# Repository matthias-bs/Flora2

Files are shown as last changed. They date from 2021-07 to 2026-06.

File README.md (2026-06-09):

# Flora2
**ESP32 Irrigation System**

> [!NOTE]
> The MicroPython software implementation is now deprecated due to ongoing issues with out-of-memory conditions and other instabilities. Instead, a new Arduino sketch is provided. 

**flora2** (MicroPython) was a derivative of [**flora1**](https://github.com/matthias-bs/Flora1).

flora2

## Features
* Running on Espressif ESP32 Microcontroller ([HiLetgo ESP-WROOM-32 ESP32 ESP-32S Development Board](http://www.hiletgo.com/ProductDetail/1906566.html)) 
* [Arduino software](14_arduino/Flora2Arduino/README_ARDUINO.md) (**New!**)
* [MicroPython](https://micropython.org/) software (**Deprecated!**)
* Plant status monitorig
    * via Xiaomi Mi Flora Plant Sensors (Bluetooth Low Energy)
    * via capacitive Soil Moisture Sensors (wired)
* Tank low / Tank empty Status Monitoring with XKC-Y25-T12V (Non-Contact Liquid Level Sensor)
* Temperature Sensor [DS18B20](https://www.maximintegrated.com/en/products/sensors/DS18B20.html) (optional)
* Weather (i.e. Temperature, Barometric Pressure and Humidity) Sensors (optional)
    * [BME280](https://www.bosch-sensortec.com/products/environmental-sensors/humidity-sensors-bme280/)
    * [M5Stack ENV III](http://docs.m5stack.com/en/hat/hat_envIII) 
* Pump Control (5 or 12 Volts) with [Infineon BTS117](https://www.infineon.com/cms/en/product/power/smart-low-side-high-side-switches/low-side-switches/classic-hitfet-24v/bts117/) _N channel vertical power FET in Smart SIPMOS® technology_
* Automatic and manual Irrigation Control with one or two Pumps
* Power Supply from [Solar Power Manager](https://www.waveshare.com/wiki/Solar_Power_Manager) with Lithium-Ion Battery and [6 V/5 W Solar Panel](https://www.waveshare.com/Solar-Panel-6V-5W.htm) (optional)
* Battery Voltage Monitoring (optional)
* Controlling and Monitoring via MQTT over WiFi

## Dashboard with [IoT MQTT Panel](https://snrlab.in/iot/iot-mqtt-panel-user-guide) (Example)

IoTMQTTPanel_flora2o_s

## References

### Arduino Software

* [NimBLE-Arduino](https://github.com/h2zero/NimBLE-Arduino) &ndash; BLE central / GATT client
* [ArduinoJson](https://github.com/bblanchon/ArduinoJson) &ndash; JSON parsing and config
* [arduino-mqtt](https://github.com/256dpi/arduino-mqtt) &ndash; MQTT client
* [OneWireNg](https://github.com/pstolarz/OneWireNg) &ndash; DS18x OneWire driver (optional)
* [M5Unit-ENV](https://github.com/m5stack/M5Unit-ENV) &ndash; SHT3x + QMP6988 temperature, humidity & barometric pressure sensor driver for ENV III (optional)
* [pocketBME280](https://github.com/angrest/pocketBME280) &ndash; BME280 temperature, humidity & barometric pressure sensor driver (optional)

### MicroPython Software (deprecated)

* [micropython-umqtt.robust2](https://pypi.org/project/micropython-umqtt.robust2/)
* [MicroPython-MiFlora](https://github.com/matthias-bs/MicroPython-MiFlora)
* [micropython-bme280](https://github.com/kevbu/micropython-bme280)
* [MicroPython-Lib/DS18X20](https://github.com/micropython/micropython-lib/tree/master/micropython/drivers/sensor/ds18x20)
* [M5_ENVIII - micropython libraries for SHT30 and QMP6988](https://github.com/cdrajb/M5_ENVIII)

----

## Disclaimer and Legal

> *Xiaomi* and *Mi Flora* are registered trademarks of *BEIJING XIAOMI TECHNOLOGY CO., LTD.*
>
> This project is a community project not for commercial use.
> The authors will not be held responsible in the event of device failure or withered plants.
>
> This project is in no way affiliated with, authorized, maintained, sponsored or endorsed by *Xiaomi* or any of its affiliates or subsidiaries.

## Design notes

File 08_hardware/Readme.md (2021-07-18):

# flora2 - Hardware

## Files
<table>
<thead>
  <tr>
    <th>File</th>
    <th>Description</th>
  </tr>
</thead>
<tbody>
  <tr>
    <td><a href="https://github.com/matthias-bs/Flora2/blob/main/08_hardware/flora2.fzz" target="_blank" rel="noopener noreferrer">flora2.fzz</a></td>
    <td>Fritzing Schematic and PCB</td>
  </tr>
  <tr>
    <td><a href="https://github.com/matthias-bs/Flora2/blob/main/08_hardware/flora2_pcb.pdf" target="_blank" rel="noopener noreferrer">flora2_pcb.pdf</a></td>
    <td>Printed Circuit Board<br></td>
  </tr>
  <tr>
    <td><a href="https://github.com/matthias-bs/Flora2/blob/main/08_hardware/flora2_sch.pdf" target="_blank" rel="noopener noreferrer">flora2_sch.pdf</a></td>
    <td>Schematic</td>
  </tr>
  <tr>
    <td><a href="https://github.com/matthias-bs/Flora2/blob/main/08_hardware/flora2_pcb_v1.0p1_patch_q4.pdf" target="_blank" rel="noopener noreferrer">flora2_pcb_v1.0p1_patch_q4.pdf</a></td>
    <td>Description of Patch p1 (Q4 Pin Mismatch)</td>
  </tr>
  <tr>
    <td><a href="https://github.com/matthias-bs/Flora2/blob/main/08_hardware/flora2_pcb_v1.0p1_patch_q4.png" target="_blank" rel="noopener noreferrer">flora2_pcb_v1.0p1_patch_q4.png</a></td>
    <td>Description of Patch p1 (Q4 Pin Mismatch)</td>
  </tr>
</tbody>
</table>

## Bugs

- Distance between D1-4 and nearby resistors too small
- U1 (voltage regulator) blocks access to Micro-USB connector
- PCB for case "BOPLA EM 220 F" too wide
  
  B_actual:  75,5
  
  B_target: 73,0
  
  -> using "BOPLA EM 217 F" instead
  
- No mounting holes for case "BOPLA EM 220 F"

  -> using "BOPLA EM 217 F" with base plate ([dxf](../12_mounting/flora2_base_plate.dxf) | [pdf](../12_mounting/flora2_base_plate.pdf))

- Wrong footprint for U1 ESP32 DevKit
  
  B_actual:  22,86mm (fits [HiLetgo ESP-32S](http://www.hiletgo.com/ProductDetail/1906566.html)!)
  
  B_target: 25,25mm (fits AZ-Delivery ESP32-DevKitC V4/JoyIt NodeMCU ESP32)
  
- Wrong footprint for Q4 ZVP2106A (**see patch p1**)
- Add pull-down resistor 10 kOhm at gate of Q3, otherwise Sensor_PWR_int wpuld be active in Deep-Sleep-Mode (**see patch p1**)

**Patch p1**
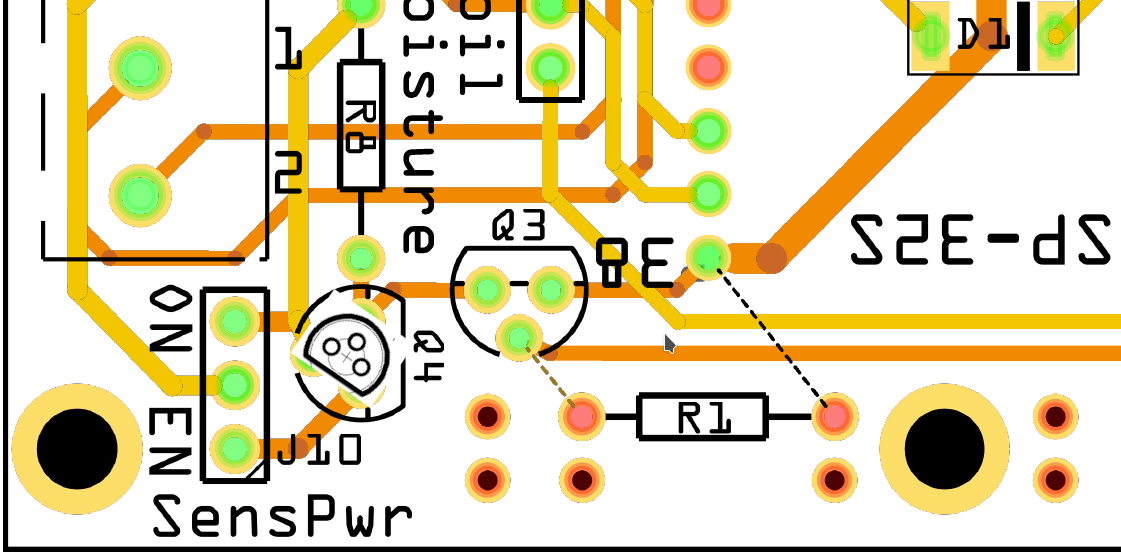
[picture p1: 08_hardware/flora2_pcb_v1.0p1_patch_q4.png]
Patch p1


## Open Issues
- add capacitors 100nF parallel to ADC inputs
- add voltage divider for Ubatt measurement as assembly option: R10=200k, R11=100k (opt.) 
- add DS18B20 + pull-up resistor 4k7 (opt.)
- add pull-down resistors for pump drivers (opt.)
- reduce Standby-Power in Deep-Sleep-Mode (opt.)
    - remove R10 or LED2 (red) from ESP-32S module

## Copyright Notice
Image: https://de.123rf.com/lizenzfreie-bilder/90587529.html

Name:

(de) Gießkanne und Blumen in Töpfen. Bewässerungssymbol lokalisiert auf weißem Hintergrund

(en) Watering can and flowers in pots. Irrigation symbol isolated on white background

File No.: 90587529

Copyright: [nikolae](https://www.123rf.com/profile_nikolae/)

Please check license on 123RF when using the image. Using the image as silkscreen print on PCB for non-commercial purposes was agreed upon by 123RF.

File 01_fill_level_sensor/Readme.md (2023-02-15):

# flora2 Tank Level Sensors

[DFRobot SEN0204 Non-contact Liquid Level Sensor XKC-Y25-T12V](https://wiki.dfrobot.com/Non-contact_Liquid_Level_Sensor_XKC-Y25-T12V_SKU__SEN0204)

Or use your favourite search engine to find the manual/"datasheet" and a supplier for the sensor **XKC Y25 T12V**. The original manufacturer seems to be hard to find...

XKC_Y25_T12V Front View

XKC_Y25_T12V Front View

XKC_Y25_T12V Back View
(I am using velcro tape to attach the sensors to the tank.)

XKC_Y25_T12V Back View

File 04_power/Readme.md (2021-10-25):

# flora2 Power Supply & Power Management

## Solar Power

https://www.waveshare.com/solar-power-manager.htm

https://www.waveshare.com/Solar-Panel-6V-5W.htm

**Note 1:**

The Solar Power Manager can supply up to 1A @5V. Please make sure that the controller (with sensors) and pump(s) do not exceed this limit.

### Battery Voltage Measurement

For battery voltage measurement, an additional wire has to be soldered to the Solar Power Manager (net label *VBAT* in the schematic, see #1 in the photo below). A small resistor (e.g. 10 Ohms) in series to the U_bat output should be added to avoid high currents in case of a short circuit.

_waveshare_solar_power_manager-1

On the flora2 PCB, an analog moisture input has to be used for voltage measurement. The following changes have to be made to adapt the battery voltage to the Analog-to-Digital Converter (ADC) input voltage range (see [Schematic](https://github.com/matthias-bs/Flora2/blob/main/08_hardware/flora2_sch.pdf)).

**Moisture4 Input -> U_bat Input**

<table>
  <tr>
    <th>Part
    <th>Value for Moisture4
    <th>Value for U_bat
  </tr>
  <tr>
    <td>R16
    <td>220k
    <td>200k
  </tr>
    <tr>
    <td>R17
    <td>330k || 100nF
    <td>100k || 100nF
  </tr>
</table>

### Battery Power Optimization

In order to save battery power, some parts of the Solar Power Manager can be modified by cutting PCB traces:
1. disconnect Battery Charge Indicator U3 with LED7..10 (see #2 in photo above)
2. disconnect Power LED (LED11, see #3 in photo below)

_waveshare_solar_power_manager-2

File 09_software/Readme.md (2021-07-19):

# flora2 Software

## Open Issues

- Sending Email reports works only partly (depending on configuration)

    Sending Email works only if sufficient memory is available due to the relative high SSL memory requirements. For example, a configuration with three analog moisture sensor leaves enough memory, another with two Miflora BLE sensor does not. At least the program handles the out-of-memory exception gracefully.

- Secure MQTT (MQTT over TLS) is kind of buggy

    As far as the MicroPython documentation goes, using the SSL Socket Wrapper or not should not make a big difference (except for memory requirements). But in fact it does! It seems the SSL Socket Object behaves different from the normal SSL Sockets regarding exceptions and polling. I racked my brain for quite a while to pin down the problem and to find a solution - to no avail yet. The current workaround is still not convincing.
    
- Compatibility to CPython / Raspberry Pi broken

    At some point, compatibility was left behind due to tweaking the code to run on **MicroPython / ESP32** - and partly in favor of new features. With some efforts, it should be possible to re-establish compatibility to **CPython / Raspberry Pi**. As a first step, the code could be modified to run on **MicroPython / Raspberry Pi**.
    The sources are quite cluttered with conditional sections concerning MicroPython and ESP32. GPIO handling is one of the inglorious examples...

Some minor points:
- Night Time Detection deserves some clean-up
- Logging / Debug Printing depending on VERBOSITY could be improved
- Wi-Fi Manager integration failed due to lack of memory
- Garbage collection is basically integrated by trial-and-error 

## Configuration

- [**secrets.py**](secrets.py) must be modified according to your WiFi, MQTT and SMTP configuration!!!
- [**config.ini**](config.ini) must be modified according to your hardware setup, plants and personal taste!
- It might be necessary to modify [**config.py**](config.py), too.

## Files

**Note:**

Due to ESP32's memory restrictions, the Python source code (**.py**) must be compiled to bytecode (**.mpy**) using **mpy-cross** (see  [MicroPython Glossary - cross-compiler](https://docs.micropython.org/en/latest/reference/glossary.html#term-cross-compiler)).

<table>
<thead>
  <tr>
    <th>File</th>
    <th>Description</th>
  </tr>
</thead>
<tbody>
  <tr>
    <td>adc1_cal.py</td>
    <td>MicroPython ESP32 ADC1 conversion using V_ref calibration value</td>
  </tr>
  <tr>
    <td>alert.py</td>
    <td>Alert class; detects Changes / Range Violations of Sensor Data and System Status, implements filter to control frequency of Email Reports</td>
  </tr>
  <tr>
    <td>bme280.py</td>
    <td>BME280 Temperature/Barometric Pressure/Humidity Sensor Library</td>
  </tr>
  <tr>
    <td>boot.py</td>
    <td>Empty MicroPython Boot Code</td>
  </tr>
  <tr>
    <td>ConfigParser.py</td>
    <td>Minimal and Functional Version of CPython's ConfigParser Module</td>
  </tr>
  <tr>
    <td>config.ini</td>
    <td><b>User's Configuration File</b></td>
  </tr>
  <tr>
    <td>config.py</td>
    <td><b>Default application settings and the Settings class with attributes from the configuration file</b></td>
  </tr>
  <tr>
    <td>flora_email.py</td>
    <td>Email class; a wrapper around umail or email.message, respectively</td>
  </tr>
  <tr>
    <td>flora_mqtt.py</td>
    <td>flora2 MQTT functions</td>
  </tr>
  <tr>
    <td>garbage_collect.py</td>
    <td>gcollect() and meminfo() Helper Functions</td>
  </tr>
  <tr>
    <td>gpio.py</td>
    <td>A stub (i.e. non-functional(!) replacement) for RPi.GPIO on other systems than Raspberry Pi</td>
  </tr>
  <tr>
    <td>irrigation.py</td>
    <td>Irrigation class; manual and automatic Irrigation</td>
  </tr>
  <tr>
    <td>main.py</td>
    <td>flora2 Main Code</td>
  </tr>
  <tr>
    <td>miflora.py</td>
    <td>MicroPython Library for Xiaomi Mi Flora (aka. flower care) BLE Plant Sensors</td>
  </tr>
  <tr>
    <td>moisture.py</td>
    <td>Moisture class; analog Moisture Sensor Reading</td>
  </tr>
  <tr>
    <td>print_line.py</td>
    <td>print_line() function; printing with time stamp and some formatting</td>
  </tr>
  <tr>
    <td>pump.py</td>
    <td>Pump class; Pump hardware control/status, software busy flag and timestamp</td>
  </tr>
  <tr>
    <td>report.py</td>
    <td>Report class; generates HTML report with various sensor/plant and system data</td>
  </tr>
  <tr>
    <td>secrets.py</td>
    <td><b>User defined constants to be kept secret</b></td>
  </tr>
  <tr>
    <td>sensor_power.py</td>
    <td>Sensor_Power class; controls the sensor power via GPIO</td>
  </tr>
  <tr>
    <td>sensor.py</td>
    <td>Sensor class; stores sensor and plant data, compares sensor data with plant data and checks sensor battery and data validity</td>
  </tr>
  <tr>
    <td>tank.py</td>
    <td>Tank class; tank fill level status values <low> and <empty> according to sensor outputs via GPIO pins</td>
  </tr>
  <tr>
    <td>temperature.py</td>
    <td>MicroPython Temperature class; DS18x20 OneWire Temperature Sensor Value</td>
  </tr>
  <tr>
    <td>umail.py</td>
    <td>uMail (MicroMail) for MicroPython</td>
  </tr>
  <tr>
    <td>weather.py</td>
    <td>Weather Sensor Data; temperature, humidity and barometric pressure from BME280 sensor connected to I2C bus interface</td>
  </tr>
  <tr>
    <td>wifi.py</td>
    <td>WiFi Connection Functions</td>
  </tr>
</tbody>
</table>

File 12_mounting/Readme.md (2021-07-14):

# flora2 Mounting Parts

<table>
    <tr>
      <th>File<th>Description
    </tr>
    <tr>
      <td>flora2_base_plate [<a href="flora2_base_plate.pdf">.pdf</a> | <a href="flora2_base_plate.dxf">.dxf</a>]
      <td>Base Plate for Mounting flora2 PCB to <a href="https://www.bopla.de/en/enclosure-technology/product/euromas-ii/-1/em-217-f.html">Bopla EM 217 F</a> Case
    </tr>
    <tr>
      <td>flora2_charger+batt [<a href="flora2_charger+batt.dxf">.dxf</a>]
      <td>Mounting Plate for <a href="https://www.bopla.de/en/enclosure-technology/product/euromas-ii/-1/em-220-f.html">Bopla EM 220 F</a> Case; Solar Power Manager and 18650 Li-Ion Cell
    </tr>
    <tr>
      <td>flora2_solar [<a href="flora2_solar.dxf">.dxf</a>]
      <td>Mounting Plate for <a href="https://www.waveshare.com/Solar-Panel-6V-5W.htm">Waveshare 6 V/5 W Solar Panel</a>
    </tr>
</table>

Size 5 hydraulic pipe clamps (acc. to DIN 3015-Part 1) can be used to fix the solar cell and charger/battery mounting plates to a 42mm balcony railing -- well, something less sophisticated might be sufficient...

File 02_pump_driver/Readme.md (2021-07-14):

# flora2 Pump Drivers

See [Infineon BTS117](https://www.infineon.com/cms/en/product/power/smart-low-side-high-side-switches/low-side-switches/classic-hitfet-24v/bts117/) _N channel vertical power FET in Smart SIPMOS® technology_ manual/datasheet.
Ensure matching power supply and pump voltages. Check that your power supply's current capability matches the pumps' current requirements -- the initial currents may exceed the nominal currents.

## Note:

The pump drivers are low-side switches -- connect pump's **plus**-wire to **positive connector of power supply** and pump's **minus**-wire to PCB terminal **P1** or **P2**, respectively.

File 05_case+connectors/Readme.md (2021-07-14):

# flora2 Case & Connectors

<table>
    <tr>
      <th>File<th>Description
    </tr>
    <tr>
      <td>flora2_outdoor_front_rev02 [<a href="outdoor/flora2_outdoor_front_rev02.pdf">.pdf</a> | <a href="outdoor/flora2_outdoor_front_rev02.dxf">.dxf</a>]
      <td>Front Plate Drilling for <a href="https://www.bopla.de/en/enclosure-technology/product/euromas-ii/-1/em-217-f.html">Bopla EM 217 F</a> Case
    </tr>
    <tr>
      <td>flora2_outdoor_label_rev01 [<a href="outdoor/flora2_outdoor_label_rev01.pdf">.pdf</a> | <a href="outdoor/flora2_outdoor_label_rev01.odg">.odg</a>]
      <td>Label for <a href="https://www.bopla.de/en/enclosure-technology/product/euromas-ii/-1/em-217-f.html">Bopla EM 217 F</a> Case Top
    </tr>
    <tr>
      <td>flora2_outdoor_wiring_rev02 [<a href="outdoor/flora2_outdoor_wiring_rev02.pdf">.pdf</a> | <a href="outdoor/flora2_outdoor_wiring.odg">.odg</a>]
      <td>PCB to Connectors Wiring Table</a>
    </tr>
</table>

## Note:

The pump drivers are low-side switches -- connect pump's **plus**-wire to **positive connector of power supply** and pump's **minus**-wire to PCB terminal **P1** or **P2**, respectively.

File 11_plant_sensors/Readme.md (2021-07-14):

# flora2 Plant Sensors

## Xiaomi Mi Flora Plant Sensor
Please refer to https://xiaomi-mi.com/home/user-manuals/ and search for *Huahuacacao Flower Care Smart Monitor* - or use your favourite search engine with the keywords *Mi Flora Plant Sensor* or *Mi Flora Flower Care* for manual/datasheet.

Mi Flora Plant Sensor

## Capacitive Soil Moisture Sensor

Use your favourite search engine with the keywords *Capacitive Soil Moisture Sensor V1.2*. For low noise add a 100nF capacitors parallel to each ADC input (i.e. parallel to R11/R13/R15/R17).

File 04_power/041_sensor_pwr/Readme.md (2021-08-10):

# LTspice Simulation of Sensor Power Circuit (Q3/Q4)

## Introduction

The LTspice simulation was done, because the sensor power circuit initially did not work. It proved that the circuit was designed properly. Further investigation revealed the Q4 footprint mismatch (see https://github.com/matthias-bs/Flora2/blob/main/08_hardware/Readme.md). 

## Setup

<table>
<thead>
  <tr>
    <th>File</th>
    <th>Description</th>
  </tr>
</thead>
<tbody>
  <tr>
    <td><a href="ZVN4206A.net" target="_blank" rel="noopener noreferrer">ZVN4206A.net</a></td>
    <td>ZETEX ZVN4206A spice model (from https://www.diodes.com/part/view/ZVN4206A)</td>
  </tr>
  <tr>
    <td><a href="ZVP2106A.net" target="_blank" rel="noopener noreferrer">ZVP2106A.net</a></td>
    <td>ZETEX ZVP2106A spice model (from https://www.diodes.com/part/view/ZVP2106A)</td>
  </tr>
  <tr>
    <td><a href="ZVN4206A.asy" target="_blank" rel="noopener noreferrer">ZVN4206A.asy</a></td>
    <td>LTspice symbol for ZVN4206A (using ZVN4206A model file)</td>
  </tr>
  <tr>
    <td><a href="ZVP2106A.asy" target="_blank" rel="noopener noreferrer">ZVP2106A.asy</a></td>
    <td>LTspice symbol for ZVP2106A (using ZVP2106A model file)</td>
  </tr>
  <tr>
    <td><a href="sensor_pwr.net" target="_blank" rel="noopener noreferrer">sensor_pwr.net</a></td>
    <td>Netlist</td>
  </tr>
  <tr>
    <td><a href="sensor_pwr.asc" target="_blank" rel="noopener noreferrer">sensor_pwr.asc</a></td>
    <td>LTspice schematic</td>
  </tr>
  <tr>
    <td><a href="sensor_pwr.plt" target="_blank" rel="noopener noreferrer">sensor_pwr.plt</a></td>
    <td>LTspice plot parameters</td>
  </tr>
  <tr>
    <td><a href="sensor_pwr.pdf" target="_blank" rel="noopener noreferrer">sensor_pwr.pdf</a></td>
    <td>Simulation plot (PDF)</td>
  </tr>
</tbody>
</table>

## Schematic
sensor_pwr_schematic

Sensor Power Switch Circuit (Load: 50 Ohms)

sensor_pwr_w_parameter_schematic

Sensor Power Switch Circuit (Load: [45 50 55 500] Ohms)

## Simulation Results

sensor_pwr_plt

Simulation Plot (Load: 50 Ohms)

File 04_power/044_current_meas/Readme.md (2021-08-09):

# Measurements

## Setup
current_measurement_setup
[Probe Image: https://commons.wikimedia.org/wiki/File:WTPC_Oscilloscope-1.jpg]

Shunt: Vishay RS-2C 0,1 Ohm / 0,5% / 2,5W
Marker: J9/Pin 9 - GPIO 0 (Pullup)

## PicoSope Settings
Ch A +/- 500mV DC
Ch B +/- 5V DC
50 s/div

Trigger B, rising edge, 1,0V 5%
Measurements: Ch A - DC Average - Between Rulers

[20210613-flora2o.pssettings](https://github.com/matthias-bs/Flora2/blob/main/04_power/044_current_meas/20210613-flora2o.pssettings)

## SW Marker

<table>
<tr>
    <th>Marker<th>Level<th>Code Section
</tr>
<tr>
    <td>#0<td>1<td>Boot done
</tr>
<tr>
    <td>#1<td>0<td>WiFi on
</tr>
<tr>
    <td>#2<td>1<td>MQTT init done
</tr>
<tr>
    <td>#3<td>0<td>Start main loop
</tr>
<tr>
    <td>#4<td>1<td>BLE start
</tr>
<tr>
    <td>#5<td>0<td>BLE end
</tr>
<tr>
    <td>#6<td>1<td>Deep sleep (Pull up)
</tr>
</table>
  
## Results

### Summary

**(flora2o-20210613-pump_off)**

- AVG (-0.05  ;0:00  ) = 3,26 mA (Deep Sleep)
- AVG ( 0:00  ;1:02  ) = 76 mA (active)
- AVG ( 0:08  ;0:09.3) = 100 mA (max. WiFi activity)
- AVG ( 0:24.3;0:46.2) = 92 mA (BLE active)

### Measurement Data

<table>
<thead>
  <tr>
    <th>File</th>
    <th>Description</th>
  </tr>
</thead>
<tbody>
  <tr>
    <td><a href="flora2o-20210613-pump_off.psdata" target="_blank" rel="noopener noreferrer">flora2o-20210613-pump_off.psdata</a></td>
    <td>Pumps off</td>
  </tr>
  <tr>
    <td><a href="flora2o-20210613-pump_1.psdata" target="_blank" rel="noopener noreferrer">flora2o-20210613-pump_1.psdata</a></td>
    <td>Pump 1 on</td>
  </tr>
  <tr>
    <td><a href="flora2o-20210613-pump_2.psdata" target="_blank" rel="noopener noreferrer">flora2o-20210613-pump_2.psdata</a></td>
    <td>Pump 2 on</td>
  </tr>
  <tr>
    <td><a href="flora2o-20210613-pump_off-solar.psdata" target="_blank" rel="noopener noreferrer">flora2o-20210613-pump_off-solar.psdata</a></td>
    <td>Solar power supply</td>
  </tr>
</tbody>
</table>

### Waveforms

<table>
<thead>
  <tr>
    <th>File</th>
    <th>Description</th>
  </tr>
</thead>
<tbody>
  <tr>
    <td><a href="waveforms/flora2o-20210613-pump_off-total_avg.pdf" target="_blank" rel="noopener noreferrer">flora2o-20210613-pump_off-total_avg.pdf</a></td>
    <td>Complete cycle, pumps off; average current</td>
  </tr>
  <tr>
    <td><a href="waveforms/flora2o-20210613-pump_off-active.pdf" target="_blank" rel="noopener noreferrer">flora2o-20210613-pump_off-active.pdf</a></td>
    <td>Complete cycle - active phase, pumps off; average current</td>
  </tr>
  <tr>
    <td><a href="waveforms/flora2o-20210613-pump_off-sleep_mode.pdf" target="_blank" rel="noopener noreferrer">flora2o-20210613-pump_off-sleep_mode.pdf</a></td>
    <td>Sleep mode; average current</td>
  </tr>
  <tr>
    <td><a href="waveforms/flora2o-20210613-pump_off-ble.pdf" target="_blank" rel="noopener noreferrer">flora2o-20210613-pump_off-ble.pdf</a></td>
    <td>BLE activity; average current</td>
  </tr>
  <tr>
    <td><a href="waveforms/flora2o-20210613-pump_off-ble_time.pdf" target="_blank" rel="noopener noreferrer">flora2o-20210613-pump_off-ble_time.pdf</a></td>
    <td>BLE activity; communication duration<br></td>
  </tr>
  <tr>
    <td><a href="waveforms/flora2o-20210613-pump_off-wifi.pdf" target="_blank" rel="noopener noreferrer">flora2o-20210613-pump_off-wifi.pdf</a></td>
    <td>WiFi activity; average current</td>
  </tr>
  <tr>
    <td><a href="waveforms/flora2o-20210613-pump_off-wifi_peak.pdf" target="_blank" rel="noopener noreferrer">flora2o-20210613-pump_off-wifi_peak.pdf</a></td>
    <td>WiFi activity; peak current</td>
  </tr>
  <tr>
    <td><a href="waveforms/flora2o-20210613-pump1-total_avg.pdf" target="_blank" rel="noopener noreferrer">flora2o-20210613-pump1-total_avg.pdf</a></td>
    <td>Complete cycle with pump 1 on; average current</td>
  </tr>
  <tr>
    <td><a href="waveforms/flora2o-20210613-pump1-avg%2Bmax.pdf" target="_blank" rel="noopener noreferrer">flora2o-20210613-pump1-avg+max.pdf</a></td>
    <td>Pump 1 on; average and max. current</td>
  </tr>
  <tr>
    <td><a href="waveforms/flora2o-20210613-pump1-ec_cycle.pdf" target="_blank" rel="noopener noreferrer">flora2o-20210613-pump1-ec_cycle.pdf</a></td>
    <td>Pump 1 on; electronic commutation cycle time</td>
  </tr>
  <tr>
    <td><a href="waveforms/flora2o-20210613-pump2-total_avg.pdf" target="_blank" rel="noopener noreferrer">flora2o-20210613-pump2-total_avg.pdf</a></td>
    <td>Complete cycle with pump 2 on; average current</td>
  </tr>
  <tr>
    <td><a href="waveforms/flora2o-20210613-pump2-avg+max.pdf" target="_blank" rel="noopener noreferrer">flora2o-20210613-pump2-avg+max.pdf</a></td>
    <td>Pump 2 on; average and max. current</td>
  </tr>
  <tr>
    <td><a href="waveforms/flora2o-20210613-pump2-ec_cycle.pdf" target="_blank" rel="noopener noreferrer">flora2o-20210613-pump2-ec_cycle.pdf</a></td>
    <td>Pump 2 on; electronic commutation cycle time<br></td>
  </tr>
  <tr>
    <td><a href="waveforms/flora2o-20210613-solar_pwr-noise.pdf" target="_blank" rel="noopener noreferrer">flora2o-20210613-solar_pwr-noise.pdf</a></td>
    <td>Solar power supply; current noise (min./max./avg.)</td>
  </tr>
  <tr>
    <td><a href="waveforms/flora2o-20210613-solar_pwr-noise_T.pdf" target="_blank" rel="noopener noreferrer">flora2o-20210613-solar_pwr-noise_T.pdf</a></td>
    <td>Solar power supply; current noise timing</td>
  </tr>
  <tr>
    <td><a href="waveforms/flora2o-20210613-solar_pwr-noise_f.pdf" target="_blank" rel="noopener noreferrer">flora2o-20210613-solar_pwr-noise_f.pdf</a></td>
    <td>Solar power supply; current noise frequency</td>
  </tr>
</tbody>
</table>

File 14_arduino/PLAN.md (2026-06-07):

# Flora2Arduino — Implementation Plan

Port of `09_software/_main.py` (MicroPython) to an Arduino/C++ sketch targeting the
ESP32 DevKit.

---

## Goals

| # | Goal |
|---|---|
| 1 | Preserve all run-time behaviour of the MicroPython version |
| 2 | Keep module boundaries so each subsystem is independently testable |
| 3 | Compile-time feature flags replace the `config.ini` `[...]_en` booleans |
| 4 | `RTC_DATA_ATTR` replaces `machine.RTC().memory()` for deep-sleep persistence |
| 5 | MQTT (arduino-mqtt) + optional HA discovery replaces `paho-mqtt` |

---

## Target Hardware

| Signal | GPIO | Notes |
|---|---|---|
| Moisture sensor 1 | 34 | ADC1 ch6, input-only |
| Moisture sensor 2 | 36 | ADC1 ch0 (SVP), input-only — avoids GPIO 35 conflict |
| Moisture sensor 3 | 32 | ADC1 ch4 |
| Moisture sensor 4 | 33 | ADC1 ch5 |
| Pump relay 1 | 19 | HIGH = on |
| Pump relay 2 | 18 | HIGH = on |
| Tank LOW switch | 23 | HIGH = triggered |
| Tank EMPTY switch | 21 | HIGH = triggered |
| Sensor power rail | 27 | HIGH = VCC on (I2C + 1-Wire) |
| DS18B20 OneWire | 5 | Optional |
| I2C SDA | 26 | ENV III / BME280 |
| I2C SCL | 25 | ENV III / BME280 |
| Battery ADC | 35 | ADC1 ch7, 100 kΩ / 200 kΩ divider → 1/3 of V_BAT |

---

## File Layout

```
Flora2Arduino/
├── Flora2Arduino.ino       Main sketch (setup / loop)
├── Flora2Cfg.h             GPIO pins, feature flags, compile-time defaults,
│                           PlantSensorData + WeatherData structs
├── secrets.h               WiFi network array, MQTT credentials, TIMEZONE_STR,
│                           NTP server list  (not committed)
├── secrets.h.example       Template for secrets.h
├── data/
│   └── config.json         Runtime config (uploaded to LittleFS)
└── src/
    ├── ConfigLoader.h/.cpp  Load AppConfig from LittleFS JSON, with defaults
    ├── Tank.h/.cpp          TankStatus (OK/LOW/EMPTY) from two GPIO inputs
    ├── Pump.h/.cpp          Timed relay with tank-abort + MQTT keep-alive CB
    ├── MoistureSensor.h/.cpp analogReadMilliVolts() → % (linear calibration)
    ├── DS1820.h/.cpp        OneWireNg_CurrentPlatform + DSTherm driver (Placeholder, no global ctor)
    ├── WeatherSensor.h/.cpp  ENV III (SHT3X + QMP6988) or BME280, I2C
    ├── MiFloraSensor.h/.cpp  NimBLE passive scan + TheengsDecoder + GATT battery
    ├── Irrigation.h/.cpp     Auto/manual irrigation logic
    ├── WiFiManager.h/.cpp    Multi-network connect, NTP sync
    └── MqttManager.h/.cpp    MQTT pub/sub, LWT, optional HA discovery
```

---

## Required Libraries

| Library | Author | Purpose |
|---|---|---|
| NimBLE-Arduino v2 | h2zero | BLE passive scan + GATT client |
| TheengsDecoder | theengs | Decode raw MiFlora advertisement JSON |
| ArduinoJson | bblanchon | config.json parsing, TheengsDecoder |
| arduino-mqtt | 256dpi | MQTT client (MQTTClient) |
| OneWireNg | pstolarz | 1-Wire bus driver + DS18xx `DSTherm` driver |
| M5Unit-ENV | m5stack | SHT3X + QMP6988 (`#ifdef WEATHER_SENSOR_ENV3`) |
| pocketBME280 | angrest | BME280 (`#ifdef WEATHER_SENSOR_BME280`) |

---

## Feature Flags (`Flora2Cfg.h`)

| Flag | Effect |
|---|---|
| `WEATHER_SENSOR_ENV3` | Include M5Unit-ENV driver (SHT3X + QMP6988) |
| `WEATHER_SENSOR_BME280` | Include Adafruit BME280 driver |
| `TEMPERATURE_SENSOR_EN` | Enable DS18B20 ambient temperature |
| `BATTERY_VOLTAGE_EN` | Enable battery ADC measurement |
| `MQTT_TLS_EN` | Use `WiFiClientSecure` + `/ca.crt` from LittleFS |
| `HA_DISCOVERY_EN` | Publish HA MQTT auto-discovery on first boot |

---

## Deep-Sleep Persistence (`RTC_DATA_ATTR`)

MicroPython uses `machine.RTC().memory()` with a packed struct.  
Arduino uses `RTC_DATA_ATTR` static variables in IRAM:

| Variable | Type | Purpose |
|---|---|---|
| `rtc_pump_last_run[2]` | `time_t` | Last successful pump run timestamp |
| `rtc_auto_irr_enabled` | `bool` | Auto irrigation on/off (MQTT controllable) |
| `rtc_sleep_disabled` | `bool` | Suppress deep sleep (MQTT controllable) |
| `rtc_man_irr_duration` | `uint32_t` | Manual irrigation duration (MQTT settable) |
| `rtc_cycle_count` | `uint32_t` | Wakeup counter (NTP re-sync trigger) |
| `rtc_first_boot` | `bool` | Clear `gSensorData[]` on first power-on |

---

## `ConfigLoader` — `AppConfig` Structure

Loaded from `data/config.json` via LittleFS.  Falls back silently to compile-time
defaults when the file is absent or a key is missing.

```
AppConfig
├── GeneralConfig
│   ├── processing_period / processing_period2 (s)
│   ├── battery_weak (mV) — switch to period2
│   ├── battery_low  (mV) — force 1-hour deep sleep
│   ├── deep_sleep / auto_irrigation
│   ├── irr_duration_auto[2], irr_duration_man (s)
│   ├── irr_rest (s) — minimum rest between irrigations
│   ├── night_begin/night_end (hr + min)
│   ├── sensor_batt_low (%)
│   └── ble_batt_interval (cycles)
├── SensorConfig
│   ├── sensor_interface: BLE | LOCAL | MQTT
│   ├── temperature_sensor, weather_sensor, battery_voltage (bool)
├── MqttConfig
│   ├── base_topic_flora, base_topic_sensors
│   ├── message_timeout (s), keepalive (s)
└── PlantConfig[5]
    ├── id, address (BLE MAC), name
    ├── pump (1-based), adc_pin (-1 = N/A)
    ├── temp_min/max, cond_min/max (µS/cm)
    ├── moist_min/lo/hi/max (%)
    └── light_min/irr/max (lux)
```

---

## `MiFloraSensor` — BLE Design

1. **Passive scan** via `NimBLEScan` for `BLE_SCAN_TIME` seconds.  
   Raw advertisement bytes are stored in a callback (no decoding during ISR).
2. **Post-scan decoding** with `TheengsDecoder::decodeBLEJson()`.  
   Each MiFlora advertisement carries exactly one property:  
   `tempc` | `moi` | `lux` | `fer` → mapped to `MIFLORA_VALID_*` bitmask bits.
3. **Smart early stop**: scan terminates as soon as all sensors in the address list
   have `valid_mask == MIFLORA_VALID_ALL (0x0F)`.
4. **GATT battery read** (every `ble_batt_interval` cycles):  
   Connect to each sensor, read characteristic `0x1a02`.  
   Results cached in NVS `Preferences` namespace `"mf_batt"` so a failed GATT read
   does not erase the last known value.

---

## `MqttManager` — MQTT Design

- Library: **arduino-mqtt** (256dpi), `MQTTClient`.
- LWT: `{base_topic_flora}/status` = `"dead"`, retain, QoS 1.  
  Published `"alive"` on connect.
- Subscribed topics: manual irrigate command, auto-irrigate enable, sleep disable,
  manual duration, incoming sensor data (MQTT sensor mode).
- **Pending-state pattern**: MQTT callback writes to `pendingXxx` fields; `loop()`
  processes them in the main thread (no shared-state races).
- Optional HA auto-discovery (`#ifdef HA_DISCOVERY_EN`): published once on
  `rtc_cycle_count == 0`.

---

## Main Loop (`loop()`)

| Step | Action |
|---|---|
| 1 | Sensor power rail ON, 200 ms warm-up |
| 2 | Read weather sensor (ENV III / BME280) |
| 3 | Read DS18B20 ambient temperature (`#ifdef TEMPERATURE_SENSOR_EN`) |
| 4 | Plant sensor data: BLE passive scan **or** local ADC **or** (pending MQTT) |
| 5 | WiFi connect + periodic NTP re-sync (every 48 cycles ≈ 12 h at 15-min period) |
| 6 | MQTT connect → process incoming messages → publish all sensor data |
| 7 | Manual irrigation (MQTT-commanded) |
| 8 | Auto irrigation (threshold + night window + rest period) |
| 9 | Sensor power rail OFF |
| 10 | Increment `rtc_cycle_count`, enter deep sleep or busy-wait |

Battery below `battery_low` → skip everything, sleep 1 h.  
Battery below `battery_weak` → use `processing_period2` (longer interval).

---

## `Irrigation` — Decision Logic

```
autoIrrigate(plant i):
  skip if: night window active
  skip if: time(now) - rtc_pump_last_run[pump] < irr_rest
  skip if: moisture >= moist_min
  skip if: light > light_irr  (bright conditions)
  skip if: tank EMPTY
  RUN pump for irr_duration_auto[pump] seconds (or until tank LOW)
  SET rtc_pump_last_run[pump] = time(now)
```

---

## Secrets File (`secrets.h`)

```cpp
// WiFi networks (tried in order)
static const WifiCreds_t WIFI_NETWORKS[] = {
    { "SSID1", "pass1" },
    { "SSID2", "pass2" },
};
static const char MQTT_HOST[] = "broker.example.com";
static const uint16_t MQTT_PORT = 1883;
static const char MQTT_USER[] = "flora2";
static const char MQTT_PASS[] = "secret";
static const char TIMEZONE_STR[] = "CET-1CEST,M3.5.0,M10.5.0/3";
static const char NTP_SERVER_1[] = "pool.ntp.org";
static const char NTP_SERVER_2[] = "time.google.com";
static const char NTP_SERVER_3[] = "";
```

---

## LittleFS Upload

Upload `data/config.json` (and optionally `data/ca.crt` for TLS) with the
**Arduino LittleFS Upload** plugin for the Arduino IDE, or via `arduino-cli`:

```
arduino-cli upload --fqbn esp32:esp32:esp32 --port /dev/ttyUSB0 \
    --input-file build/flora2arduino.ino.bin
# then upload filesystem image separately with esptool or the IDE plugin
```

---

## Known Design Decisions / Deviations from MicroPython

| Topic | MicroPython | Arduino |
|---|---|---|
| Deep-sleep persistence | `machine.RTC().memory()` + `struct.pack` | `RTC_DATA_ATTR` |
| BLE | `micropython-bluetooth` + raw GAP | NimBLE-Arduino v2 |
| MQTT | `umqtt.robust` | arduino-mqtt (256dpi) |
| Config | `config.ini` + `ConfigParser` | `config.json` + ArduinoJson |
| Weather sensor | `bme280.py` / `qmp6988.py` | M5Unit-ENV / pocketBME280 (angrest) |
| GPIO 35 conflict | Both `UBATT_ADC` and `moisture[1]` on 35 | Moisture[1] moved to GPIO 36 |
| DS1820 | `temperature.py` (DS18B20 via OneWire) | `OneWireNg_CurrentPlatform` + `DSTherm` (pstolarz); `Placeholder<>` avoids global construction |

---

## Session Updates (2026-06-01)

Recent implementation and debugging changes made while porting and validating the Arduino sketch.

- BLE: Removed passive advertisement-based MiFlora decoding and `TheengsDecoder` dependency. Replaced with reliable direct GATT reads (write control char, short delay, read data char).
- MiFlora: GATT read sequence implemented; RSSI captured; battery readings cached in NVS (`Preferences`) so failed reads do not erase last-known battery values.
- MQTT: Topics and payloads adjusted — plant sensors published under `{base_topic_flora}/sensor/{id}`, and `lux` renamed to `light` in JSON payloads. Added more verbose publish diagnostics (logs publish result, `_client.lastError()`/`returnCode()`).
- Timezone / NTP: `TIMEZONE_STR` default located in `Flora2Cfg.h`; `setenv("TZ", TIMEZONE_STR, 1); tzset();` now executed in `setup()` every boot so deep-sleep cycles observe correct localtime/DST.
- Pump last-run timestamps: `publishPumpLastRun()` added (epoch + ISO8601). Guarding added to avoid recording any pump `last_run` when system time is not yet NTP-synced (prevents bogus epochs like 970). The device logs a warning instead.
- Weather sensor (ENV III): `WeatherSensor` now logs an I²C bus scan when init fails and probes the hardware-reported addresses (SHT3x at 0x44, QMP6988 observed at 0x70 on some modules). Code uses single fixed hardware addresses.
- ArduinoJson: Deprecated `containsKey()` calls replaced with safe checks using `.isNull()` / `.as<T>()`.
- Cleanup: Removed stale passive-scan defines and `TheengsDecoder` from `package.json`; added I²C scan helper and other small diagnostic helpers.

Pending items / follow-ups:

- Gather full serial logs for a complete connect/publish/disconnect cycle to diagnose intermittent MQTT publish failures (WiFi association drops observed).  
- Optionally add build-time control to suppress NimBLE debug logs and document usage.  
- If you prefer to record event timestamps even when NTP is not yet available, we can implement a provisional RTC/monotonic mapping to convert later after sync — advise if desired.

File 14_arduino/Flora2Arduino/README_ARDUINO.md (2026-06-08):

# Flora2 Arduino Sketch — Documentation

## 1. Introduction

Flora2 Arduino is a C++ / Arduino port of the Flora2 plant irrigation controller, originally written in MicroPython. It targets ESP32 DevKit-style boards and provides:

- Automated irrigation driven by capacitive moisture sensors.
- Manual irrigation via MQTT commands.
- MiFlora BLE plant sensor reads via direct GATT (temperature, moisture, light, conductivity, battery, RSSI).
- I²C weather sensor support — M5Stack ENV III (SHT3x + QMP6988) or BME280.
- MQTT telemetry and control with optional Home Assistant discovery.
- Deep sleep cycles with state persistence across resets (`RTC_DATA_ATTR`).

---

## 2. Set-up and Installation

### Prerequisites

- Arduino CLI or Arduino IDE with ESP32 board support (Arduino core 3.3.8 recommended).
- Required libraries — see [Acknowledgements](#5-acknowledgements).
- `data/config.json` uploaded to the board's LittleFS partition and a `secrets.h` file with WiFi and MQTT credentials.
- Optional secure MQTT setup: set `MQTT_PORT` to `8883`, define `MQTT_TLS_EN`, and upload the broker CA certificate as `data/root_ca.pem` in LittleFS.
- Optional (not recommended): define `MQTT_TLS_ALLOW_INSECURE_FALLBACK` to allow insecure TLS only when loading `root_ca.pem` fails.

> [!NOTE]
> The certificate file must include `-----BEGIN CERTIFICATE-----` and `-----END CERTIFICATE-----`.

### Building and uploading

1. Open the `14_arduino/Flora2Arduino/Flora2Arduino.ino` sketch in Arduino IDE or `arduino-cli`.
2. Install the required libraries (see [Acknowledgements](#5-acknowledgements)).
3. Copy `secrets.h.example` to `secrets.h` and fill in your WiFi networks and MQTT broker credentials.
4. **Compile and upload** — preferred via Arduino IDE: *Sketch → Upload*. Alternatively, use the included VS Code tasks or the build script:

```bash
# Compile
bash .vscode/arduino-compile-runner.sh compile
# Upload — replace /dev/ttyUSB0 with your serial port
bash .vscode/arduino-compile-runner.sh upload --port /dev/ttyUSB0
```

### Uploading the LittleFS filesystem

Place your `config.json` at `data/config.json` inside the sketch folder, then use the Arduino LittleFS Upload plugin or `arduino-cli` to flash the filesystem image.

### Configuration

- **Runtime** — `data/config.json` defines plant identities, sensor interface mode (BLE / LOCAL / MQTT), moisture thresholds, and irrigation durations. See `ConfigLoader` for the full schema.
- **Optional stale-sensor safeguard** — `general.stale_sensor_max_age_s` controls sensor freshness for auto irrigation. `0` disables guarding; values `>0` enable it with max allowed sensor age in seconds.
- **Compile-time** — `Flora2Cfg.h` contains hardware pin assignments and feature flags such as `WEATHER_SENSOR_ENV3`, `TEMPERATURE_SENSOR_EN`, and `MQTT_TLS_EN`.
- **MQTT transport** — plain MQTT uses the broker port configured in `secrets.h` (commonly `1883`). For TLS, enable `MQTT_TLS_EN`, set `MQTT_PORT` to `8883`, and provide `data/root_ca.pem` so `MqttManager` can validate the broker certificate. If you explicitly define `MQTT_TLS_ALLOW_INSECURE_FALLBACK`, the sketch can fall back to insecure TLS when CA loading fails.
- **Default PCB wiring note** — moisture sensor 2 input and battery voltage ADC are both routed to GPIO 35 on the default Flora2 hardware. Changing either signal to a different GPIO requires a PCB hardware patch.
- **Timezone / DST** — `TIMEZONE_STR` in `Flora2Cfg.h` sets the POSIX timezone string (e.g. `"CET-1CEST,M3.5.0,M10.5.0/3"`). Edit it to match your location before compiling.

---

## 3. Usage

### Serial output

Diagnostics are written to the serial console at 115200 baud. Useful output includes I²C bus scans, BLE GATT reads, MQTT publish results, and per-plant irrigation decisions.

> [!NOTE]
> To enable detailed log output (`log_d`, `log_i`, `log_w`, `log_e`), open **Tools → Core Debug Level** and select a level above **None** (for example **Info** or **Debug**), then recompile and upload.

### MQTT topics

The base topic defaults to `flora2` and can be overridden in `config.json` or `Flora2Cfg.h`.

| Topic | Description |
|---|---|
| `flora2/status` | Device status — see note below |
| `flora2/ubatt` | Battery voltage in mV |
| `flora2/weather` | JSON: `{"temperature":…,"humidity":…,"pressure":…}` |
| `flora2/sensor/{plant_id}` | Per-plant JSON: `{"temperature":…,"moisture":…,"light":…,"conductivity":…,"battery":…,"rssi":…}` |
| `flora2/pump{N}/last_run` | Retained JSON: `{"epoch":…,"iso":"YYYY-MM-DDTHH:MM:SS+hhmm","trigger":"auto|manual|unknown"}`; refreshed every cycle |
| `flora2/pump{N}/status` | Retained `"on"` / `"off"`; refreshed every cycle |
| `flora2/sleep_dis_status` | Retained `"1"` / `"0"`; deep-sleep disabled/enabled |
| `flora2/man_irr_duration_status` | Manual irrigation duration in seconds; refreshed every cycle, not retained |
| `flora2/auto_irr_duration1_status` | Auto irrigation duration for pump 1 in seconds; refreshed every cycle, not retained |
| `flora2/auto_irr_duration2_status` | Auto irrigation duration for pump 2 in seconds; refreshed every cycle, not retained |

**Status topic:** the device publishes `"online"` on connect and `"sleeping"` before a graceful disconnect. The MQTT Last Will and Testament (LWT) is configured to publish `"dead"` (retained, QoS 1) — but only if the client drops without a clean disconnect. After a normal cycle `"sleeping"` is always the last value written by the device itself.

### Manual irrigation commands

| Topic | Payload | Effect |
|---|---|---|
| `flora2/man_irr_cmd` | pump number (e.g. `2`) | Trigger a manual run on that pump |
| `flora2/man_irr_duration_ctrl` | duration in seconds | Override the manual irrigation duration (all pumps) |
| `flora2/auto_irr_duration1_ctrl` | duration in seconds | Override the auto irrigation duration for pump 1 |
| `flora2/auto_irr_duration2_ctrl` | duration in seconds | Override the auto irrigation duration for pump 2 |
| `flora2/auto_irr_ctrl` | `1` / `0` | Enable / disable automatic irrigation |

The device publishes the corresponding status topics `man_irr_duration_status`, `auto_irr_duration1_status`, and `auto_irr_duration2_status` on every MQTT cycle without the retain flag. The other device status topics remain retained.

### Receiving commands across deep sleep

On every wakeup the device reconnects to the broker and re-subscribes to all control topics at QoS 1. If a message was published with the **retain flag**, the broker re-delivers it immediately on subscribe — so the device always receives the current setting value, regardless of how long it was sleeping.

The received values are written to `RTC_DATA_ATTR` variables (`rtc_auto_irr_enabled`, `rtc_man_irr_duration`, `rtc_auto_irr_duration[2]`, `rtc_sleep_disabled`) which survive deep-sleep resets for the rest of the power-on session.

> [!NOTE]
> The examples below use `mosquitto_pub` because it makes the required topic, payload, retain, and QoS settings explicit. You can use any MQTT client that supports the same options, including GUI tools such as MQTT Explorer.

**Persistent settings** — publish with `-r` (retain) and `-q 1` (QoS 1). The retain flag ensures the broker re-delivers the value on every reconnect. QoS 1 guarantees the broker acknowledges receipt and, on Mosquitto, persists the retained message to disk so it survives a broker restart:

```bash
# Disable automatic irrigation (persists across sleep)
mosquitto_pub -h <broker> -q 1 -r -t "flora2/auto_irr_ctrl" -m "0"

# Re-enable automatic irrigation
mosquitto_pub -h <broker> -q 1 -r -t "flora2/auto_irr_ctrl" -m "1"

# Set manual irrigation duration to 30 s (persists across sleep)
mosquitto_pub -h <broker> -q 1 -r -t "flora2/man_irr_duration_ctrl" -m "30"

# Set auto irrigation duration for pump 1 to 45 s (persists across sleep)
mosquitto_pub -h <broker> -q 1 -r -t "flora2/auto_irr_duration1_ctrl" -m "45"

# Set auto irrigation duration for pump 2 to 120 s (persists across sleep)
mosquitto_pub -h <broker> -q 1 -r -t "flora2/auto_irr_duration2_ctrl" -m "120"

# Disable deep sleep (persists across sleep)
mosquitto_pub -h <broker> -q 1 -r -t "flora2/sleep_dis_ctrl" -m "1"
```

**One-shot commands** — `man_irr_cmd` is published **with** the retain flag (`-r`) and QoS 1. The device executes it once, then publishes a retained `"0"` back to the broker to clear the stored value. On subsequent wakeups the broker re-delivers `"0"`, which the device ignores. A power-cycle (cold boot) also sees `"0"` and does not re-fire.

```bash
# Trigger pump 1 — can be sent at any time, including while the device is sleeping
mosquitto_pub -h <broker> -q 1 -r -t "flora2/man_irr_cmd" -m "1"
```

> [!NOTE]
> The device guards against duplicate delivery by comparing the received pump number against `rtc_last_man_irr_cmd` (stored in `RTC_DATA_ATTR`). If the broker reset publish fails and the same value is re-delivered on the next wakeup, the command is silently ignored rather than re-fired.

### Automatic irrigation

Auto irrigation runs during each main cycle after sensor reads, even if WiFi or MQTT are unavailable. For every plant configured in automatic mode in `config.json`, the `Irrigation` engine decides whether to activate its pump.

When WiFi/MQTT are down, irrigation still executes with the latest locally available state (BLE/LOCAL sensor interfaces, plus `RTC_DATA_ATTR` overrides). In MQTT sensor mode, auto irrigation may be skipped if no recent sensor data is available. MQTT telemetry and remote commands are best-effort and resume on reconnect.

**Trigger condition** — a pump run is initiated when all of the following hold:

- Measured moisture is below the plant's `moist_min` threshold.
- The rest cooldown (`irr_rest`) has elapsed since the last run.
- The current time is outside the configured night window.
- The tank level sensor reports sufficient water.

**Safety interlocks** — any one of the following blocks a pump run:

| Interlock | Detail |
|---|---|
| **Tank empty** | `TANK_EMPTY` float switch (GPIO 21) is checked before and during every run; the pump stops immediately if the tank empties to prevent dry running. |
| **Tank low** | `TANK_LOW` float switch (GPIO 23) is polled during a run; the run completes but the result is flagged `TANK_LOW` and logged. |
| **Night window** | Irrigation is suppressed between `night_begin` and `night_end` (set in `config.json`; noise prevention). |
| **Rest period** | The `irr_rest` cooldown must have elapsed since `last_run` before the pump can fire again. (allow for seepage) |
| **High light intensity** | Per-plant `light_irr` threshold: irrigation is suppressed when ambient lux exceeds this value to reduce the risk of leaf burn. |
| **Stale sensor guard (optional)** | Enabled by `stale_sensor_max_age_s > 0`: if all valid sensors mapped to a pump are older than the configured age, that pump is skipped for the cycle. |
| **Battery critically low** | If battery voltage is below `battery_low` (mV), the device skips the main cycle entirely and enters a 1-hour deep sleep. |

Manual irrigation commands bypass the auto-decision logic for the current cycle but still respect the tank-empty interlock.

**Published every cycle:**

- Retained `pump{N}/status` and `pump{N}/last_run` are refreshed for every pump on each MQTT cycle.
- `man_irr_duration_status`, `auto_irr_duration1_status`, and `auto_irr_duration2_status` are also published every cycle, but without the retain flag.
- `last_run` includes `trigger` to indicate whether the stored run was caused by `manual` or `auto` irrigation (`unknown` before the first successful run).
- If a pump ran, `last_run` contains the updated timestamp; otherwise the previous stored timestamp is published again unchanged.
- If the clock is not yet synced, the stored timestamp is left unchanged and a warning is logged when a run occurs before time is valid.

---

## 4. Implementation details

### Architecture

| Component | Role |
|---|---|
| `Flora2Arduino.ino` | `setup()` and `loop()`: hardware init, sensor reads, WiFi/NTP, MQTT, irrigation, deep sleep |
| `ConfigLoader` | Loads `AppConfig` from LittleFS `config.json` |
| `WeatherSensor` | Driver for ENV III (SHT3x + QMP6988) or BME280 |
| `MiFloraSensor` | Direct BLE GATT reads; battery cached in NVS |
| `Irrigation` | Decision engine: night window, moisture thresholds, rest times, tank checks |
| `MqttManager` | Publish / subscribe helpers, LWT, HA discovery |
| `WiFiMgr` | WiFi connection and NTP sync |

### Class diagram

```mermaid
classDiagram
    Flora2Arduino <|-- MqttManager
    Flora2Arduino <|-- Irrigation
    Flora2Arduino <|-- MiFloraSensor
    Flora2Arduino <|-- WeatherSensor
    Flora2Arduino <|-- WiFiMgr

    class Flora2Arduino {
      +setup()
      +loop()
    }
    class MqttManager {
      +connect()
      +publishSensorData()
      +publishPumpLastRun()
    }
    class Irrigation {
      +autoIrrigate()
      +manualIrrigate()
    }
    class MiFloraSensor {
      +readBattery()
      +readGATT()
    }
    class WeatherSensor {
      +begin()
      +read()
    }
    class WiFiMgr {
      +connect()
      +ntpSync()
    }
```

### Main loop

```mermaid
flowchart TD
  Start[Start loop] --> PowerOn[Power sensors ON]
  PowerOn --> ReadWeather[Read weather sensor]
  ReadWeather --> ReadPlants[Read plant sensors]
  ReadPlants --> WiFi[WiFi connect + NTP sync]
  WiFi --> MQTT[MQTT connect]
  MQTT --> Publish[Publish telemetry]
  Publish --> Manual[Handle manual irrigation]
  Manual --> Auto[Auto irrigation decision]
  Auto --> TankCheck{Tank level OK?}
  TankCheck -- No --> Skip[Skip pump run]
  TankCheck -- Yes --> RunPump[Run pump]
  Skip --> PublishPump[Publish pump last-run/status]
  RunPump --> PublishPump
  PublishPump --> PowerOff[Power sensors OFF]
  PowerOff --> Sleep[Deep sleep or wait]
```

### Key implementation notes

- **Timezone / DST** — `setenv("TZ", TIMEZONE_STR, 1); tzset();` is called on every boot so that `localtime()` returns correct local time after deep-sleep resets (the TZ environment variable is not retained across sleep).
- **Pump last-run metadata** — timestamps are updated only when `time(nullptr)` returns a plausible value (post-2021), confirming a valid NTP sync. The trigger source (`auto` / `manual`) is persisted per pump in `RTC_DATA_ATTR` and included in the published `pump{N}/last_run` JSON.
- **BLE** — passive advertisement scanning has been removed; direct GATT reads provide reliable sensor values. Battery readings are cached in NVS to survive cycles where the GATT connection fails.
- **Weather sensor detection** — the driver performs an I²C bus scan on init failure and logs all found addresses, making hardware wiring problems straightforward to diagnose from serial output.
- **ENV III driver vendored** — the SHT3X, QMP6988, and I2C_Class sources from M5Unit-ENV are vendored into `src/env3/` instead of declaring the library as a dependency. The published M5Unit-ENV library pulls in the entire M5UnitUnified framework and its cascading transitive dependencies, which is impractical for a standalone sketch. The three driver files are self-contained, MIT-licensed, and only `WeatherSensor.cpp` includes them.

---

## 5. Acknowledgements

| Library | Author | Purpose |
|---|---|---|
| [NimBLE-Arduino](https://github.com/h2zero/NimBLE-Arduino) | h2zero | BLE central / GATT client |
| [ArduinoJson](https://github.com/bblanchon/ArduinoJson) | bblanchon | JSON parsing and config |
| [arduino-mqtt](https://github.com/256dpi/arduino-mqtt) | 256dpi | MQTT client |
| [OneWireNg](https://github.com/pstolarz/OneWireNg) | pstolarz | DS18x OneWire driver (optional) |
| [M5Unit-ENV](https://github.com/m5stack/M5Unit-ENV) | m5stack | SHT3x + QMP6988 driver for ENV III (optional) |
| [pocketBME280](https://github.com/angrest/pocketBME280) | angrest | BME280 driver (optional) |

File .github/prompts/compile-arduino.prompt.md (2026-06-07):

---
mode: agent
description: >
  Compile the current Arduino sketch using arduino-cli.
  Reads fqbn from .vscode/arduino.json and deduces the sketch path
  from the active editor file. Surfaces any compiler errors as inline
  diagnostics and explains them.
tools:
  - run_in_terminal
  - get_errors
  - read_file
---

# Compile Arduino Sketch

## What this skill does
1. Reads `.vscode/arduino.json` to obtain the `fqbn` (fully-qualified board name).  
2. Deduces the sketch folder from the currently active file: walks upward until a
  `.ino` file is found; falls back to `14_arduino/Flora2Arduino` if none is found.  
3. Invokes `.vscode/arduino-compile-runner.sh compile` (which calls the repo wrapper
   and then arduino-cli) and captures the output.  
4. Reports any errors or warnings as a numbered list referencing file + line.  
5. For each error, provides a brief explanation and a suggested fix.

## Parameters provided by the calling agent or user

| Name | Where it comes from |
|---|---|
| Active file path | Editor context (`${file}`) |
| Workspace root | `${workspaceFolder}` |

## Execution steps

Run the compile using the runner script. The `WORKSPACE_FOLDER` env variable is set
so the helper can find `arduino.json` without a hard-coded path:

```bash
WORKSPACE_FOLDER="${workspaceFolder}" \
  bash "${workspaceFolder}/.vscode/arduino-compile-runner.sh" compile \
  --active "${file}"
```

After the command finishes:
- Exit code 0 → report "Compilation succeeded" and the flash/RAM usage summary.
- Exit code non-zero → collect all lines matching `error:|warning:` and present them
  as an annotated list. Offer to open each offending file and jump to the problem line.

## Fallback behaviour

If `.vscode/arduino.json` is missing or contains no `fqbn`:
- Warn the user: "arduino.json not found or missing fqbn — using default ESP32 Dev Module".
- Use fallback: `esp32:esp32:esp32`.

## Not in scope for this skill
- Uploading to hardware (use the `upload-arduino` task or the `arduino-dev` agent).
- Serial monitoring.

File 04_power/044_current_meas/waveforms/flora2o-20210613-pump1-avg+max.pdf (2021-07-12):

Channel Name | Span | Value | Min | Max | Average σ
-A/0,1 | DC Average Between rulers 495,3 mA 495,3 mA 495,3 mA 495,3 mA 0 A
-A/0,1 | Maximum | Between rulers 995,4 mA 995,4 mA 995,4 mA 995,4 mA 0 A
1 | 2 | Δ | 1/Δ
Time Axis 58,29 s 1m20,0 s 21,62 s 46,26 mHz

13.06.2021 21:31:55

matthias-bs PicoScope 6 Version 6.14.44.5870 PicoScope 2205A

### flora2o - Pump1; AVG/Max

3,0

2,0

1,0

0,0

-1,0

-2,0

-3,0

-4,0

5,0

-5,0

V
DC
0,8

0,6

0,4

0,2

0,0

-0,2

-0,4

-0,6

-0,8

1,0

-1,0

A

56,56 | 59,06 | 1m2,0 | 1m4,0 | 1m7,0 | 1m9,0 | 1m12,0 | 1m14,0 | 1m17,0 | 1m19,0 | 1m22,0
s

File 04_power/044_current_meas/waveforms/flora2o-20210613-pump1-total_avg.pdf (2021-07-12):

Channel Name | Span | Value | Min Max Average σ
-A/0,1 | DC Average Between rulers 171,6 mA 0 A 0 A 0 A | 0 A
1 | 2 | Δ | 1/Δ
Time Axis 0,0 s 1m35,0 s 1m35,0 s 10,53 mHz

13.06.2021 21:31:55

matthias-bs PicoScope 6 Version 6.14.44.5870 PicoScope 2205A flora2o - Pump1; Total AVG

3,0

2,0

1,0

0,0

-1,0

-2,0

-3,0

-4,0

5,0

-5,0

V
DC
0,8

0,6

0,4

0,2

0,0

-0,2

-0,4

-0,6

-0,8

1,0

-1,0

A

-5,0 | 5,0 | 15,0 | 25,0 | 35,0 | 45,0 | 55,0 | 1m5,0 | 1m15,0 | 1m25,0 | 1m35,0
s

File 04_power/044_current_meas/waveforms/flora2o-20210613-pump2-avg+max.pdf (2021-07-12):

Channel Name | Span | Value | Min | Max | Average σ
-A/0,1 | Maximum | Whole trace | 1,124 A | 1,124 A | 1,124 A | 1,124 A | 0 A
-A/0,1 | DC Average Between rulers 650,5 mA 650,5 mA 650,5 mA 650,5 mA 0 A
1 | 2 | Δ | 1/Δ
Time Axis 45,91 s 1m7,0 s 21,22 s 47,12 mHz

13.06.2021 21:34:31

matthias-bs PicoScope 6 Version 6.14.44.5870 PicoScope 2205A

### flora2o - Pump2; AVG/Max

3,0

2,0

1,0

0,0

-1,0

-2,0

-3,0

-4,0

5,0

-5,0

V
DC
0,8

0,6

0,4

0,2

0,0

-0,2

-0,4

-0,6

-0,8

1,0

-1,0

A

43,76 | 46,26 | 48,76 | 51,26 | 53,76 | 56,26 | 58,76 | 1m1,0 | 1m4,0 | 1m6,0 | 1m9,0
s

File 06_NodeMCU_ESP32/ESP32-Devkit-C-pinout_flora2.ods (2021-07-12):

 | ESP32-Devkit-C
 | 3V3 |  |  |  |  | Gnd
 | EN Used by program logic. SW2 grounds via resistor. |  |  |  |  | GPIO23, VSPID, HS1_STROBE | Tank_low
 |  |  |  |  |  | GPIO22, VSPIWP, U0RTS, EMAC_TXD1
 |  |  |  |  |  | GPIO1, U0TXD, CLK_OUT3, EMAC_RXD2
Moisture_1 | GPIO34, ADC1_CH6, RTC_GPIO4 |  |  |  |  | GPIO3, U0RXD, CLK_OUT2
Moisture_2 | GPIO35, ADC1_CH7, RTC_GPIO5 |  |  |  |  | GPIO21, VSPIHD, EMAC_TX_EN | Tank_empty
Moisture_3 | GPIO32, 32K_XP (32.768 kHz osc i/p),ADC1_CH4, TOUCH9, RTC_GPIO9 |  |  |  |  | Gnd
Moisture_4 | GPIO33, 32K_XN (32.768 kHz osc o/p),ADC1_CH5, TOUCH8, RTC_GPIO8 |  |  |  |  | GPIO19, VSPIQ, U0CTS, EMAC_TXD0 | Pump1_ctrl
I2C1_SCL | GPIO25, DAC_1, ADC2_CH8, RTC_GPIO6, EMAC_RXD0 |  |  |  |  | GPIO18, VSPICLK, HS1_DATA7 | Pump2_ctrl
I2C1_SDA | GPIO26, DAC_2, ADC2_CH9, RTC_GPIO7, EMAC_RXD1 |  |  |  |  | GPIO5, VSPICS0, HS1_DATA6, EMAC_RX_CLK | Temperature
Sensor_en | GPIO27, ADC2_CH7, TOUCH7, RTC_GPIO17, EMAC_RX_DV |  |  |  |  | GPIO17, HS1_DATA5, U2TXD, EMAC_CLK_OUT_180
J7-4 | GPIO14, ADC2_CH6, TOUCH6, RTC_GPIO16, MTMS, HSPI-CLK, HS2_CLK, SD_CLK, EMAC_TXD2 |  |  |  |  | GPIO16, HS1_DATA4, U2RXD, EMAC_CLK_OUT
J7-2 | GPIO12, ADC2_CH5, TOUCH5, RTC_GPIO15, MTDI, HSPIQ,HS2_DATA2, SD_DATA2, EMAC_TXD3 |  |  |  |  | GPIO4, ADC2_CH0, TOUCH0, RTC_GPIO10, HSPIHD,HS2_DATA1, SD_DATA1, EMAC_TX_ER
 | Gnd |  |  |  |  | GPIO0, ADC2_CH1, TOUCH1, RTC_GPIO11, CLK_OUT1,EMAC_TX_CLK
J7-3 | GPIO13, ADC2_CH4, TOUCH4, RTC_GPIO14, MTCK, HSPID,HS2_DATA3, SD_DATA3, EMAC_RX_ER |  |  |  |  | GPIO2, ADC2_CH2, TOUCH2, RTC_GPIO12, HSPIWP,HS2_DATA0, SD_DATA0 External pulldown
 | GPIO9, SD_DATA2, SPIHD, HS1_DATA2, U1RXD |  |  |  |  | GPIO15, ADC2_CH3, TOUCH3, RTC_GPIO13, MTDO,HSPICS0, HS2_CMD, SD_CMD, EMAC_RXD3
 | GPIO10, SD_DATA3, SPIWP, HS1_DATA3, U1TXD |  |  |  |  | GPIO8, SD_DATA1, SPID, HS1_DATA1, U2CTS
 | Marked Gnd Something odd here: caused crashes when I used it. Avoid. |  |  |  |  | GPIO7, SD_DATA0, SPIQ, HS1_DATA0, U2RTS
 | 5V |  |  |  |  | GPIO6, SD_CLK, SPICLK, HS1_CLK, U1CTS
 |  |  |  |  |  | Used for internal flash, not recommended for other use
 | ADC: FSD = 4095 = 1.109V (Because 693mV gave 2559. Is the limit 1.0V?) |  |  |  |  | Input only. No internal pullup or pulldown.
 |  |  |  |  |  | Used by USB/REPL
 |  |  |  |  |  | GPIO0 has a 5KΩ external pullup. SW0 grounds via 470Ω
 | DAC: FSD = 255 = 3.19V (Vs = 3.3V). 127 gave 1.63V implying 3.3V FS. | Value | Expected | Actual | Error % | Used on ESP32-WROVER-KIT etc to access external SPI RAM
 |  | 10 | 0,13 | 0,21 | 2,4
 | SPI: Hardware SPI ID1 is HSPI, ID2 is VSPI. Any pins may be used - native pins are faster. | 20 | 0,26 | 0,33 | 2,1
 | ID1 MISO 12 MOSI 13 CLK 14 | 127 | 1,64 | 1,63 | -0,3
 | ID2 MISO 19 MOSI 23 CLK 18 | 200 | 2,58 | 2,53 | -1,5
 |  | 240 | 3,11 | 3,01 | -3
 |  | 255 | 3,3 | 3,19 | -3,3
 | On models with psRAM this pin GPIO12 (MTD) must not be pulled low on boot. https://forum.micropython.org/viewtopic.php?f=18&t=3553&start=280 |  |  |  |  | ESP32-D2WD is the chip with embedded 2MB flash and the internal flash is connected to different pins (GPIO16, GPIO17, SD_CMD, SD_CLK, SD_DATA_0 and SD_DATA_1 )

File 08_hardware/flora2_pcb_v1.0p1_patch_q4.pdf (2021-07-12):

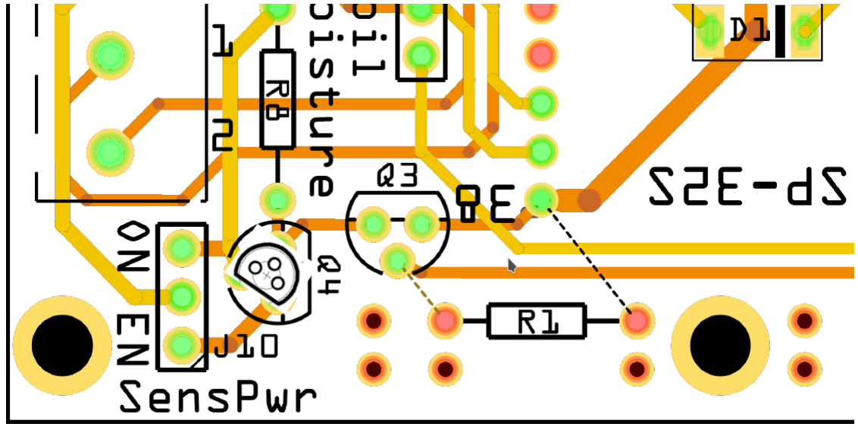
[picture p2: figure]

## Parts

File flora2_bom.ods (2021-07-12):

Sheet: Platine
Pos. | Menge |  |  |  | Einheit | Teil | Bestellnummer | Link | Preis/Einheit | Preis
 | Indoor |  | Outdoor |  |  |  |  |  |  | Indoor |  | Outdoor
 | min | max | min | max |  |  |  |  |  | min | max | min | max
1 | 1 | 1 | 1 | 1 | Stk | Flora2 Platine | n.a. | http://aisler.net | 10,80 € | 10,80 € | 10,80 € | 10,80 € | 10,80 €
2 | 1 | 1 | 1 | 1 | Stk | HiLetgo ESP-32S | n.a. | https://smile.amazon.de/gp/product/B0718T232Z | 14,17 € | 14,17 € | 14,17 € | 14,17 € | 14,17 €
3 | 1 | 4 |  |  | Stk | TVS-Diode SMLVT3V3 | SMLVT3V3 STM |  | 0,20 € | 0,20 € | 0,80 € | 0,00 € | 0,00 €
4 | 1 | 1 | 1 | 1 | Stk | MOSFET N-Kanal ZVN 4206 A | ZVN 4206 A |  | 0,93 € | 0,93 € | 0,93 € | 0,93 € | 0,93 €
5 | 1 | 1 | 1 | 1 | Stk | MOSFET P-Kanal ZVP 2106 A | ZVP 2106 A |  | 1,16 € | 1,16 € | 1,16 € | 1,16 € | 1,16 €
6 | 1 | 2 | 1 | 2 | Stk | Smart Low Side Power Schalter, 60V, 3,5A BTS 117 | BTS 117 |  | 2,30 € | 2,30 € | 4,60 € | 2,30 € | 4,60 €
7 | 1 | 1 |  |  | Stk | DC-DC-Wandler 5V/500mA R-78E50-05 | R-78E50-05 |  | 6,60 € | 6,60 € | 6,60 € | 0,00 € | 0,00 €
8 | 1 | 1 |  |  | Stk | Widerstand 100R 0,25W | 1/4W 100 |  | 0,03 € | 0,03 € | 0,03 € | 0,00 € | 0,00 €
9 | 2 | 2 | 2 | 2 | Stk | Widerstand 330R 0,25W | 1/4W 330 |  | 0,03 € | 0,07 € | 0,07 € | 0,07 € | 0,07 €
10 | 2 | 2 | 2 | 2 | Stk | Widerstand 470R 0,25W | 1/4W 470 |  | 0,03 € | 0,07 € | 0,07 € | 0,07 € | 0,07 €
11 | 2 | 2 | 2 | 2 | Stk | Widerstand 560R 0,25W | 1/4W 560 |  | 0,03 € | 0,06 € | 0,06 € | 0,06 € | 0,06 €
12 | 3 | 3 | 3 | 3 | Stk | Widerstand 10k 0,25W | 1/4W 10K |  | 0,03 € | 0,09 € | 0,09 € | 0,09 € | 0,09 €
13 | 1 | 4 |  |  | Stk | Widerstand 220k 1% 0,6W | VI MBB02070C2203 |  | 0,04 € | 0,04 € | 0,16 € | 0,00 € | 0,00 €
14 | 1 | 4 |  |  | Stk | Widerstand 330k 1% 0,6W | VI MBB02070C3303 |  | 0,04 € | 0,04 € | 0,16 € | 0,00 € | 0,00 €
15 | 2 | 4 |  |  | Stk | Lötbare Schraubklemme - 3-pol, RM 5,08 mm, 90° | RND 205-00233 |  | 0,26 € | 0,52 € | 1,04 € | 0,00 € | 0,00 €
16 | 2 | 1 |  |  | Stk | Lötbare Schraubklemme - 2-pol, RM 5,08 mm, 90° | RND 205-00232 |  | 0,25 € | 0,50 € | 0,25 € | 0,00 € | 0,00 €
17 | 2 | 2 | 2 | 2 | Stk | 20pol. Buchsenleiste, gerade, RM 2,54, H: 7,0mm | BL 1X20G7 2,54 |  | 0,99 € | 1,98 € | 1,98 € | 1,98 € | 1,98 €
18 | 1 | 1 | 1 | 1 | Stk | 40pol. Stiftleiste, gerade, RM 2,54 | SL 1X40G 2,54 |  | 0,22 € | 0,22 € | 0,22 € | 0,22 € | 0,22 €
19 |  | 1 |  | 1 | Stk | Jumper 2,54 mm, schwarz | JUMPER 2,54 SW |  | 0,02 € | 0,00 € | 0,02 € | 0,00 € | 0,02 €
20 |  |  |  |  |  |  |  |  |  | 0,00 € | 0,00 € | 0,00 € | 0,00 €
21 |  |  |  |  |  |  |  |  |  | 0,00 € | 0,00 € | 0,00 € | 0,00 €
22 |  |  |  |  |  |  |  |  |  | 0,00 € | 0,00 € | 0,00 € | 0,00 €
23 |  |  |  |  |  |  |  |  |  | 0,00 € | 0,00 € | 0,00 € | 0,00 €
24 |  |  |  |  |  |  |  |  |  | 0,00 € | 0,00 € | 0,00 € | 0,00 €
25 |  |  |  |  |  |  |  |  |  | 0,00 € | 0,00 € | 0,00 € | 0,00 €
26 |  |  |  |  |  |  |  |  |  | 0,00 € | 0,00 € | 0,00 € | 0,00 €
27 |  |  |  |  |  |  |  |  |  | 0,00 € | 0,00 € | 0,00 € | 0,00 €
28 |  |  |  |  |  |  |  |  |  | 0,00 € | 0,00 € | 0,00 € | 0,00 €
 |  |  |  |  |  |  |  |  | Summe | 39,78 € | 43,21 € | 31,84 € | 34,16 €

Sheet: Gehäuse+Steckverbinder
Pos. | Menge |  |  |  | Einheit | Teil | Bestellnummer | Link | Preis/Einheit | Preis
 | Indoor |  | Outdoor |  |  |  |  |  |  | Indoor |  | Outdoor
 | min | max | min | max |  |  |  |  |  | min | max | min | max
1 | 1 | 1 |  |  | Stk | BOPLA U 110 Gehäuse Serie Unimas, 110 x 107 x 60 mm, IP40 | BOPLA U 110 | https://www.reichelt.de/universal-gehaeuse-110-x-107-x-60-mm-ip40-bopla-u-110-p5768.html | 11,50 € | 11,50 € | 11,50 € | 0,00 € | 0,00 €
2 | 1 | 1 |  |  | Stk | Lumberg KFV 50 (Füllstandssensor) | LUM KFV 50 | https://www.reichelt.de/einbaukupplung-frontmontage-ip40-5-pol-180--lum-kfv-50-p116110.html | 3,20 € | 3,20 € | 3,20 € | 0,00 € | 0,00 €
3 | 1 | 4 |  |  | Stk | Lumberg KFV 30 (Bodenfeuchtesensor) | LUM KFV 30 | https://www.reichelt.de/einbaukupplung-frontmontage-ip40-3-pol-lum-kfv-30-p238947.html | 2,90 € | 2,90 € | 11,60 € | 0,00 € | 0,00 €
4 | 1 | 1 |  |  | Stk | Lumberg SFV50/6 (Pumpen) | LUM SFV 50/6 | https://www.reichelt.de/einbaustecker-frontmontage-ip40-5-polig-lum-sfv-50-6-p167557.html | 3,80 € | 3,80 € | 3,80 € | 0,00 € | 0,00 €
5 | 1 | 1 |  |  | Stk | Lumberg 1614-19 Einbaukupplung Hohlstecker 5,6mm/2,1mm (Netzteil) | LUM 1614-19 | https://www.reichelt.de/einbaukupplung-fuer-hohlstecker-aussen-5-6mm--innen-2-1mm-lum-1614-19-p237595.html | 1,90 € | 1,90 € | 1,90 € | 0,00 € | 0,00 €
6 |  |  | 1 | 1 | Stk | BOPLA EM 217 F Gehäuse Serie Euromas II, 122 x 120 x 57 mm | BOPLA EM 217 F | https://www.reichelt.de/gehaeuse-serie-euromas-ii-122-x-120-x-57-mm-ip65-bopla-em-217-f-p126206.html | 17,70 € | 0,00 € | 0,00 € | 17,70 € | 17,70 €
7 |  |  | 2 | 3 | Stk | Lumberg Quicklock-Einbaukupplung - Größe 12, 2 pol (Power, Pumpen) | LUM 0270-02 | https://www.reichelt.de/quicklock-einbaukupplung-groesse-12-2-pol-lum-0270-02-p239487.html | 2,80 € | 0,00 € | 0,00 € | 5,60 € | 8,40 €
8 |  |  | 2 | 2 | Stk | Lumberg Quicklock-Einbaukupplung - Größe 12, 4 pol (Füllstandssensoren) | LUM 0270-04 | https://www.reichelt.de/quicklock-einbaukupplung-groesse-12-4-pol-lum-0270-04-p239489.html | 3,70 € | 0,00 € | 0,00 € | 7,40 € | 7,40 €
9 |  |  |  | 1 | Stk | Lumberg Quicklock-Einbaukupplung - Größe 12, 6 pol (Wettersensor) | LUM 0270-06 | https://www.reichelt.de/quicklock-einbaukupplung-groesse-12-6-pol-lum-0270-06-p239491.html | 4,34 € | 0,00 € | 0,00 € | 0,00 € | 4,34 €
10 |  |  |  | 1 | Stk | Micro-USB Einbaubuchse Wasserdicht | n.a. | https://smile.amazon.de/dp/B07ZCZ8NL1 | 12,73 € | 0,00 € | 0,00 € | 0,00 € | 12,73 €
11 |  | 1 |  |  | Stk | USB-Adapter FT, 1 x USB 2.0 B-Buchse > 1 x USB 2.0 A-Buchse | CLIFF CP30207NX | https://www.reichelt.de/usb-adapter-ft-1-x-usb-2-0-b-buchse-1-x-usb-2-0-a-buchse-cliff-cp30207nx-p227644.html | 4,30 € | 0,00 € | 4,30 € | 0,00 € | 0,00 €
12 |  |  |  |  |  |  |  |  |  | 0,00 € | 0,00 € | 0,00 € | 0,00 €
13 |  |  |  |  |  |  |  |  |  | 0,00 € | 0,00 € | 0,00 € | 0,00 €
14 |  |  |  |  |  |  |  |  |  | 0,00 € | 0,00 € | 0,00 € | 0,00 €
15 |  |  |  |  |  |  |  |  |  | 0,00 € | 0,00 € | 0,00 € | 0,00 €
16 |  |  |  |  |  |  |  |  |  | 0,00 € | 0,00 € | 0,00 € | 0,00 €
17 |  |  |  |  |  |  |  |  |  | 0,00 € | 0,00 € | 0,00 € | 0,00 €
18 |  |  |  |  |  |  |  |  |  | 0,00 € | 0,00 € | 0,00 € | 0,00 €
19 |  |  |  |  |  |  |  |  |  | 0,00 € | 0,00 € | 0,00 € | 0,00 €
20 |  |  |  |  |  |  |  |  |  | 0,00 € | 0,00 € | 0,00 € | 0,00 €
21 |  |  |  |  |  |  |  |  |  | 0,00 € | 0,00 € | 0,00 € | 0,00 €
22 |  |  |  |  |  |  |  |  |  | 0,00 € | 0,00 € | 0,00 € | 0,00 €
23 |  |  |  |  |  |  |  |  |  | 0,00 € | 0,00 € | 0,00 € | 0,00 €
 |  |  |  |  |  |  |  |  | Summe | 23,30 € | 36,30 € | 30,70 € | 50,57 €

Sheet: Spannungsversorgung
Pos. | Menge |  |  |  | Einheit | Teil | Bestellnummer | Link | Preis/Einheit | Preis
 | Indoor |  | Outdoor |  |  |  |  |  |  | Indoor |  | Outdoor
 | min | max | min | max |  |  |  |  |  | min | max | min | max
1 | 1 | 1 |  |  | Stk | Steckernetzteil, 25 W, 12 V, 2,08 A | MW GST25E12 | https://www.reichelt.de/steckernetzteil-25-w-12-v-2-08-a-mw-gst25e12-p171098.html | 12,11 € | 12,11 € | 12,11 € | 0,00 € | 0,00 €
2 |  |  | 1 | 1 | Stk | Lumberg Quicklock Gr. 12 Stecker 2pol. | LUM 0250-02 | https://www.reichelt.de/quicklock-stecker-groesse-12-2-pol-lum-0250-02-p239473.html | 4,80 € | 0,00 € | 0,00 € | 4,80 € | 4,80 €
3 |  |  | 1 | 1 | Stk | Lumberg Quicklock Gr. 12 Kupplung 2pol. | LUM 0260-02 | https://www.reichelt.de/quicklock-kupplung-groesse-12-2-pol-lum-0260-02-p239480.html | 3,40 € | 0,00 € | 0,00 € | 3,40 € | 3,40 €
4 |  |  | 1 | 1 | Stk | Industriezelle, Li-Ion, 18650, 3,7 V, 1600 mAh | LIMG GDIHR18650Z | https://www.reichelt.de/industriezelle-li-ion-18650-3-7-v-1600-mah-z-loetfahnen-limg-gdihr18650z-p86881.html | 7,20 € | 0,00 € | 0,00 € | 7,20 € | 7,20 €
5 |  |  | 1 | 1 | Stk | JST - Buchsengehäuse, 1x2-polig – PH | JST PH2P BU | https://www.reichelt.de/jst-buchsengehaeuse-1x2-polig-ph-jst-ph2p-bu-p185041.html | 0,05 € | 0,00 € | 0,00 € | 0,05 € | 0,05 €
6 |  |  | 1 | 1 | Stk | 5m Nylon USB C Kabel, USB 2.0, schwarz, USB A auf USB Typ C Ladekabel | n.a. | https://smile.amazon.de/gp/product/B085CG6HLF | 11,99 € | 0,00 € | 0,00 € | 11,99 € | 11,99 €
7 |  |  | 1 | 1 | Stk | Solarpanel, 6 V / 5 W | DEBO SOLAR 5W | https://www.reichelt.de/entwicklerboards-solarpanel-5-w-debo-solar-5w-p266039.html | 12,90 € | 0,00 € | 0,00 € | 12,90 € | 12,90 €
8 |  |  | 1 | 1 | Stk | Solar Ladegerät für 6 bis 24 V Panels | DEBO PWR SOLAR2 | https://www.reichelt.de/entwicklerboards-solar-ladegeraet-fuer-6-bis-24-v-panels-debo-pwr-solar2-p266038.html | 9,99 € | 0,00 € | 0,00 € | 9,99 € | 9,99 €
9 |  |  | 2 | 2 | Stk | JST - Crimpkontakt, Buchse – PH | JST PH CKB | https://www.reichelt.de/jst-crimpkontakt-buchse-ph-jst-ph-ckb-p185071.html | 0,03 € | 0,00 € | 0,00 € | 0,06 € | 0,06 €
10 |  |  | 1 | 2 | Stk | Rohrschelle Hydraulikrohr 42mm, Einzelrohrschelle | n.a. | https://www.ebay.de/itm/202800309155 | 2,69 € | 0,00 € | 0,00 € | 2,69 € | 5,38 €
11 |  |  |  |  |  |  |  |  |  | 0,00 € | 0,00 € | 0,00 € | 0,00 €
12 |  |  |  |  |  |  |  |  |  | 0,00 € | 0,00 € | 0,00 € | 0,00 €
13 |  |  |  |  |  |  |  |  |  | 0,00 € | 0,00 € | 0,00 € | 0,00 €
14 |  |  |  |  |  |  |  |  |  | 0,00 € | 0,00 € | 0,00 € | 0,00 €
15 |  |  |  |  |  |  |  |  |  | 0,00 € | 0,00 € | 0,00 € | 0,00 €
16 |  |  |  |  |  |  |  |  |  | 0,00 € | 0,00 € | 0,00 € | 0,00 €
17 |  |  |  |  |  |  |  |  |  | 0,00 € | 0,00 € | 0,00 € | 0,00 €
18 |  |  |  |  |  |  |  |  |  | 0,00 € | 0,00 € | 0,00 € | 0,00 €
19 |  |  |  |  |  |  |  |  |  | 0,00 € | 0,00 € | 0,00 € | 0,00 €
20 |  |  |  |  |  |  |  |  |  | 0,00 € | 0,00 € | 0,00 € | 0,00 €
21 |  |  |  |  |  |  |  |  |  | 0,00 € | 0,00 € | 0,00 € | 0,00 €
22 |  |  |  |  |  |  |  |  |  | 0,00 € | 0,00 € | 0,00 € | 0,00 €
23 |  |  |  |  |  |  |  |  |  | 0,00 € | 0,00 € | 0,00 € | 0,00 €
 |  |  |  |  |  |  |  |  | Summe | 12,11 € | 12,11 € | 53,08 € | 55,77 €

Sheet: Sensoren+Aktoren
Pos. | Menge |  |  |  | Einheit | Teil | Bestellnummer | Link | Preis/Einheit | Preis
 | Indoor |  | Outdoor |  |  |  |  |  |  | Indoor |  | Outdoor
 | min | max | min | max |  |  |  |  |  | min | max | min | max
1 | 2 | 2 | 2 | 2 | Stk | XKC-Y25-NPN Füllstandssensor | n.a. | https://smile.amazon.de/dp/B07DFLPQWP | 5,89 € | 11,78 € | 11,78 € | 11,78 € | 11,78 €
2 | 1 | 2 |  |  | Stk | Tauchpumpe 12V Giant Electric Tech Inc. AD20P-1230C | n.a. | https://smile.amazon.de/dp/B08594GR9M | 13,49 € | 13,49 € | 26,98 € | 0,00 € | 0,00 €
3 |  |  |  |  | Stk | Tauchpumpe 5V | n.a. | https://smile.amazon.de/dp/B07N1F14FX | 9,99 € | 0,00 € | 0,00 € | 0,00 € | 0,00 €
 |  |  | 1 | 1 | Stk | Tauchpumpe 5V Decdeal 4.8W USB | n.a. | https://smile.amazon.de/gp/product/B07B4W9YHP
4 | 1 | 4 |  |  | Stk | Entwicklerboards - Feuchtesensor (Bodenfeuchte) | DEBO CAP SENS | https://www.reichelt.de/entwicklerboards-feuchtesensor-bodenfeuchte--debo-cap-sens-p223620.html | 2,71 € | 2,71 € | 10,84 € | 0,00 € | 0,00 €
5 | 1 | 4 |  |  | Stk | Schalengehäuse, Hammond Serie 1551, 35 x 50 x 15 mm, schwarz | 1551FBK | https://www.reichelt.de/schalengehaeuse-serie-1551-35-x-50-x-15-mm-schwarz-1551fbk-p221225.html | 1,35 € | 1,35 € | 5,40 € | 0,00 € | 0,00 €
6 | 1 | 1 |  |  | Stk | Lumberg KV 50/6 (Pumpe) | LUM KV 50-6 | https://www.reichelt.de/kupplung-kv-50-6-rundsteckv-gerade-ip40-5-polig-lang-lum-kv-50-6-p175237.html | 4,80 € | 4,80 € | 4,80 € | 0,00 € | 0,00 €
7 |  |  | 1 | 2 | Stk | Lumberg Quicklock Gr. 12 Stecker 2pol. (Pumpe) | LUM 0250-02 | https://www.reichelt.de/quicklock-stecker-groesse-12-2-pol-lum-0250-02-p239473.html | 4,80 € | 0,00 € | 0,00 € | 4,80 € | 9,60 €
8 | 1 | 4 |  |  | Stk | Lumberg SV 30 (Bodenfeuchtesensor) | LUM SV 30 | https://www.reichelt.de/stecker-sv-30-rundsteckverbinder-gerade-ip40-3-pol-lum-sv-30-p132829.html | 4,25 € | 4,25 € | 17,00 € | 0,00 € | 0,00 €
9 | 1 | 1 |  |  | Stk | Lumberg SV 50 (Füllstandssensor) | LUM SV 50 | https://www.reichelt.de/stecker-sv-50-rundsteckverbinder-gerade-ip40-5-pol-180--lum-sv-50-p248561.html | 4,15 € | 4,15 € | 4,15 € | 0,00 € | 0,00 €
10 |  |  | 2 | 2 | Stk | Lumberg Quicklock Gr. 12 Stecker 4pol. (Füllstandssensor) | LUM 0250-04 | https://www.reichelt.de/quicklock-stecker-groesse-12-4-pol-lum-0250-04-p239475.html | 5,55 € | 0,00 € | 0,00 € | 11,10 € | 11,10 €
11 |  |  |  | 1 | Stk | Schutzhülle für Außensensoren | 2018175 | https://shop.watterott.com/Schutzhuelle-fuer-Aussensensoren | 10,00 € | 0,00 € | 0,00 € | 0,00 € | 10,00 €
12 |  |  |  | 1 | Stk | Entwicklerboards - Temperatur-, Feuchtigkeits- und Drucksensor | DEBO BME280 | https://www.reichelt.de/entwicklerboards-temperatur-feuchtigkeits-und-drucksensor--debo-bme280-p253982.html | 5,45 € | 0,00 € | 0,00 € | 0,00 € | 5,45 €
13 |  |  |  | 1 | Stk | Lumberg Quicklock Gr. 12 Stecker 6pol. (Wettersensor) | LUM 0250-06 | https://www.reichelt.de/quicklock-stecker-groesse-12-6-pol-lum-0250-06-p239477.html | 6,14 € | 0,00 € | 0,00 € | 0,00 € | 6,14 €
14 |  | 1 |  |  | Stk | DS 18B20 Digital Thermometer, 1-wire +/- 0,5°C, TO-92 | DS 18B20 | https://www.reichelt.de/digital-thermometer-1-wire--0-5-c-to-92-ds-18b20-p58169.html | 2,90 € | 0,00 € | 2,90 € | 0,00 € | 0,00 €
15 |  |  |  |  | Stk | 5m Nylon USB C Kabel, USB 2.0, schwarz, USB A auf USB Typ C Ladekabel | n.a. | https://smile.amazon.de/gp/product/B085CG6HLF | 11,99 € | 0,00 € | 0,00 € | 0,00 € | 0,00 €
16 |  |  | 0 | 2 | Stk | Pöppelmann Kapsto GPN 215 ML 17x20 (Schutzkappe für LUM 0250-x) | GPN 215 ML 17x20 |  |  | 0,00 € | 0,00 € | 0,00 € | 0,00 €
17 |  |  | 1 | 2 | Stk | 2er-Set 4in1-Pflanzensensoren mit Bluetooth und App-Kontrolle | NC9594 | https://www.pearl.de/a-NC9594-3506.shtml | 43,99 € | 0,00 € | 0,00 € | 43,99 € | 87,98 €
18 |  |  |  |  |  |  |  |  |  | 0,00 € | 0,00 € | 0,00 € | 0,00 €
19 |  |  |  |  |  |  |  |  |  | 0,00 € | 0,00 € | 0,00 € | 0,00 €
20 |  |  |  |  |  |  |  |  |  | 0,00 € | 0,00 € | 0,00 € | 0,00 €
21 |  |  |  |  |  |  |  |  |  | 0,00 € | 0,00 € | 0,00 € | 0,00 €
22 |  |  |  |  |  |  |  |  |  | 0,00 € | 0,00 € | 0,00 € | 0,00 €
23 |  |  |  |  |  |  |  |  |  | 0,00 € | 0,00 € | 0,00 € | 0,00 €
 |  |  |  |  |  |  |  |  | Summe | 42,53 € | 83,85 € | 71,67 € | 142,05 €

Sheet: Wasserbehälter+Verteilung
Pos. | Menge |  |  |  | Einheit | Teil | Bestellnummer | Link | Preis/Einheit | Preis
 | Indoor |  | Outdoor |  |  |  |  |  |  | Indoor |  | Outdoor
 | min | max | min | max |  |  |  |  |  | min | max | min | max
1 | 1 | 2 |  |  | m | Rain Bird Zufuhrschlauch 4mm | 20200806429 | https://www.gbk-shop.de/rain-bird-zufuhrschlauch-4mm | 0,99 € | 0,99 € | 1,98 € | 0,00 € | 0,00 €
2 | 3 | 8 |  |  | m | Gardena Tropfschlauch 2mm | 20200806428 | https://www.gbk-shop.de/gardena-tropfschlauch-2mm | 1,39 € | 4,17 € | 11,12 € | 0,00 € | 0,00 €
3 | 1 | 2 |  |  | Stk | Gardena Tropfverteiler | 20200724319 | https://www.gbk-shop.de/gardena-tropfverteiler | 6,95 € | 6,95 € | 13,90 € | 0,00 € | 0,00 €
4 | 1 | 2 |  |  | Stk | Gardena Überwurfmutter | 20200724320 | https://www.gbk-shop.de/gardena-ueberwurfmutter | 1,29 € | 1,29 € | 2,58 € | 0,00 € | 0,00 €
5 | 4 | 12 |  |  | Stk | Tropfschlauchhalter 2mm | 20200724298 | https://www.gbk-shop.de/tropfschlauchhalter-2mm | 0,29 € | 1,16 € | 3,48 € | 0,00 € | 0,00 €
6 |  |  | 6 | 6 | Stk | T-Stück 4mm | 20200713110-001 | https://www.gbk-shop.de/t-stueck-4mm | 0,75 € | 0,00 € | 0,00 € | 4,50 € | 4,50 €
7 | 1 | 2 | 1 | 2 | Stk | Schlauchverbinder gerade Reduzierer 8 mm 4 mm Kunststoff | n.a. | https://www.ebay.de/itm/122059338467 | 1,85 € | 1,85 € | 3,70 € | 1,85 € | 3,70 €
8 | 1 | 1 |  |  | Stk | Eurobox 40l 60x40x20cm³ | EAN 2007532090002 | https://www.bauhaus.info/kunststoffboxen/bauhaus-eurobehaelter/p/10753209 | 8,95 € | 8,95 € | 8,95 € | 0,00 € | 0,00 €
9 | 1 | 1 |  |  | Stk | Fachteiler für Eurobox | EAN 5413995021274 | https://www.bauhaus.info/kunststoffboxen/bauhaus-fachteiler/p/23095003 | 6,25 € | 6,25 € | 6,25 € | 0,00 € | 0,00 €
10 | 1 | 2 | 1 | 1 | m | Aquarienschlauch 8x1mm | EAN 4003991097130 | https://www.bauhaus.info/gartenschlaeuche/aquariumschlauch-meterware/p/16175812 | 1,25 € | 1,25 € | 2,50 € | 1,25 € | 1,25 €
11 |  |  |  |  | m | Aquarienschlauch 4x1mm | EAN 4003991097123 | https://www.bauhaus.info/gartenschlaeuche/aquariumschlauch-meterware/p/16175805 | 0,99 € | 0,00 € | 0,00 € | 0,00 € | 0,00 €
12 |  |  | 1 | 1 | Stk | Maischefass 31l |  | https://www.bauhaus.info/maischefaesser-getraenkefaesser/floraworld-classic-maischefass/p/16125460 | 22,95 € | 0,00 € | 0,00 € | 22,95 € | 22,95 €
13 | 1 | 1 |  |  | Stk | Glattblech 500 x 250 mm, Stärke: 0,8 mm, Aluminium, Blank |  | https://www.bauhaus.info/glattbleche/kantoflex-glattblech/p/10244684 | 3,95 € | 3,95 € | 3,95 € | 0,00 € | 0,00 €
14 | 4 | 8 |  |  | Stk | Sechskantmutter M3, Edelstahl, A4 |  | https://www.bauhaus.info/sechskantmuttern/marinetech-sechskantmutter/p/23679805 | 0,06 € | 0,24 € | 0,48 € | 0,00 € | 0,00 €
15 | 4 | 8 | 2 | 2 | Stk | Gewindeschraube M3x10, A4, Edelstahl, Innensechskant, Linsenkopf |  | https://www.bauhaus.info/gewindeschrauben/marinetech-gewindeschraube/p/23679887 | 0,08 € | 0,32 € | 0,64 € | 0,16 € | 0,16 €
16 |  |  |  |  |  |  |  |  |  | 0,00 € | 0,00 € | 0,00 € | 0,00 €
17 |  |  |  |  |  |  |  |  |  | 0,00 € | 0,00 € | 0,00 € | 0,00 €
18 |  |  |  |  |  |  |  |  |  | 0,00 € | 0,00 € | 0,00 € | 0,00 €
19 |  |  |  |  |  |  |  |  |  | 0,00 € | 0,00 € | 0,00 € | 0,00 €
20 |  |  |  |  |  |  |  |  |  | 0,00 € | 0,00 € | 0,00 € | 0,00 €
21 |  |  |  |  |  |  |  |  |  | 0,00 € | 0,00 € | 0,00 € | 0,00 €
22 |  |  |  |  |  |  |  |  |  | 0,00 € | 0,00 € | 0,00 € | 0,00 €
23 |  |  |  |  |  |  |  |  |  | 0,00 € | 0,00 € | 0,00 € | 0,00 €
 |  |  |  |  |  |  |  |  | Summe | 37,37 € | 59,53 € | 30,71 € | 32,56 €

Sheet: Gesamtsystem
 | Preis
 | Indoor |  | Outdoor
 | min | max | min | max
Platine | 39,78 € | 43,21 € | 31,84 € | 34,16 €
Gahäuse+Steckverbinder | 23,30 € | 36,30 € | 30,70 € | 50,57 €
Spannungsversorgung | 12,11 € | 12,11 € | 53,08 € | 55,77 €
Sensoren+Aktoren | 42,53 € | 83,85 € | 71,67 € | 142,05 €
Wasserbehälter+Verteilung | 37,37 € | 59,53 € | 30,71 € | 32,56 €
Summe | 155,09 € | 235,00 € | 218,00 € | 315,11 €

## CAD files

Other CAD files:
05_case+connectors/drawing_frame.dxf
05_case+connectors/outdoor/flora2_outdoor_front_rev02.dxf
12_mounting/flora2_solar.dxf
12_mounting/flora2_charger+batt.dxf
12_mounting/flora2_base_plate.dxf

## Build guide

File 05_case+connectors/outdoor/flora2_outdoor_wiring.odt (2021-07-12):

Flora2 Outdoor – Verkabelung

V0.1 10.03.2021

Einbaustecker/ -buchsen | Pin | Signal | Leitung extern | Leitung intern
Lumberg Quicklock 12 | 1 | GND | | sw
| 2 | power | | rt
Lumberg Quicklock 12 | 1 | GND | bl | sw
| 2 | power | br | rt
| 3 | output | ge | gn
| 4 | mode | sw | -
Lumberg Quicklock 12 | 1 | GND | | sw
| 2 | 3V3 | | rt
| 3 | SCL | | ge
| 4 | SDA | | gn
| 5 | n.c. | - | -
| 6 | n.c. | - | -

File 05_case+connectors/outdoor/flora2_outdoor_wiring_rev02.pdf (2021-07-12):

# Flora2 Outdoor – Verkabelung

V0.2 29.04.2021

Einbaubuchsen (Lumberg Quicklock 12) | Pin | Signal | Leitung extern | Leitung intern
| 1 | GND | | sw
| 2 | power | | rt
| 3 | ubat | | gn

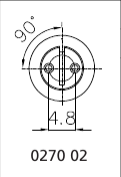
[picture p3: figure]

1 | GND | sw
2 | power | rt
1 | GND | bl | sw
2 | power | br | rt
3 | output | ge | gn
4 | mode | sw | -

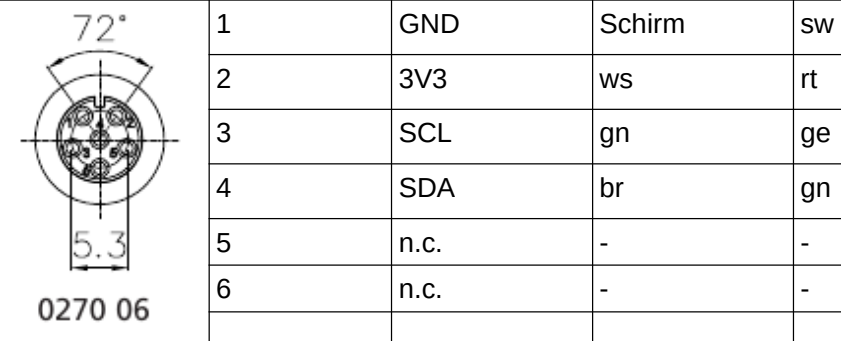
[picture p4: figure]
GND; Schirm; SCL; SDA

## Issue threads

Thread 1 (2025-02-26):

Check/implement Home Assistant integration

matthias-bs, 2025-02-26:
https://www.home-assistant.io/integrations/plant

```yaml
# Example configuration.yaml entry
plant:
  "Flower Box":
    sensors:
      moisture: sensor.s6_moisture
      battery: sensor.s6_battery
      temperature: sensor.s6_temperature
      conductivity: sensor.s6_conductivity
      brightness: sensor.s6_brightness
    min_moisture: 20

mqtt:
  sensor:
    - name: s6_moisture
      state_topic: "flora2o/Sensor6"
      value_template: "{{ value_json.moisture | int }}"
      unit_of_measurement: "%"
    - name: s6_battery
      state_topic: "flora2o/Sensor6"
      value_template: "{{ value_json.battery | int }}"
      unit_of_measurement: "%"
    - name: s6_temperature
      state_topic: "flora2o/Sensor6"
      value_template: "{{ value_json.temperature | float }}"
      unit_of_measurement: "°C"
    - name: s6_conductivity
      state_topic: "flora2o/Sensor6"
      value_template: "{{ value_json.conductivity | int }}"
      unit_of_measurement: "µS/cm"
    - name: s6_brightness
      state_topic: "flora2o/Sensor6"
      value_template: "{{ value_json.light | int }}"
      unit_of_measurement: "lx"

```

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

Closed 2025-03-04.

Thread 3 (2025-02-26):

Add M5Stack ENV III support (temperature, humidity and pressure sensor)

matthias-bs, 2025-02-26:
http://docs.m5stack.com/en/hat/hat_envIII

- SHT30 (temperature, humidity)
- QMP6988 (pressure)

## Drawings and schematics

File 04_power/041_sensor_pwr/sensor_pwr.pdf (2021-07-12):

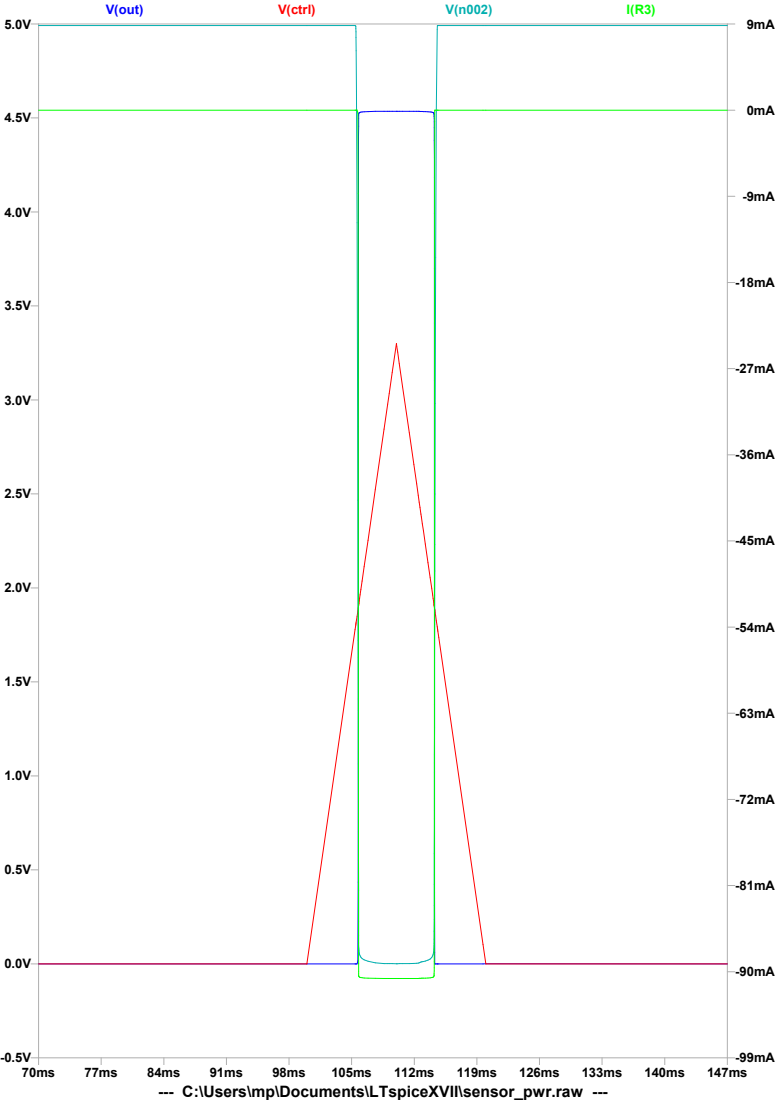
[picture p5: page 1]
V(out); V(ctrl)

--- C:\Users\mp\Documents\LTspiceXVII\sensor_pwr.raw ---

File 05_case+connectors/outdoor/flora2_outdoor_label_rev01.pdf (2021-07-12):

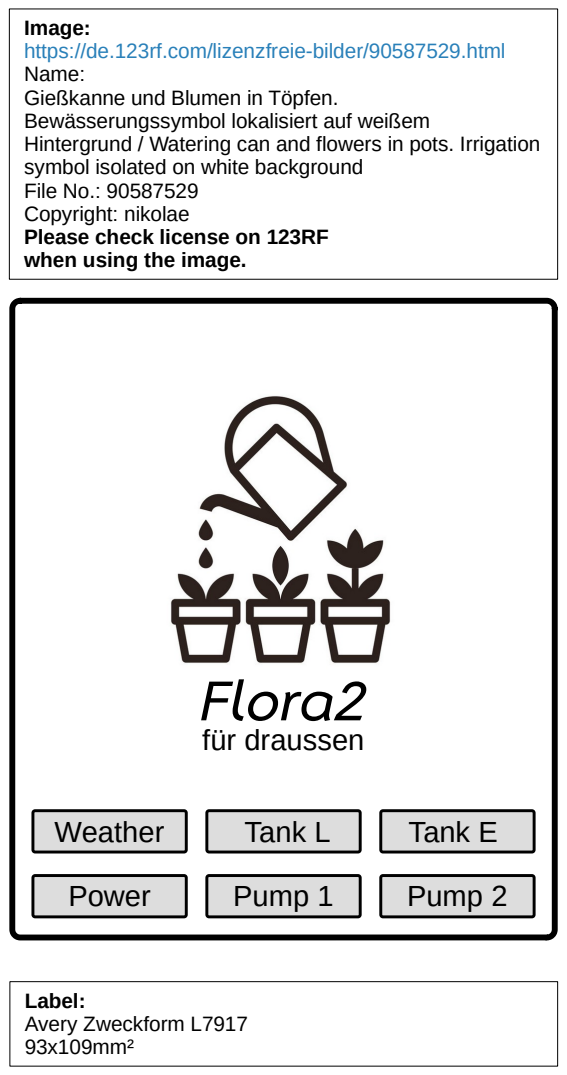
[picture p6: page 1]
Weather; Flora2; für draussen; Pump 1; Pump 2; Tank L; Tank E; Power; Label: Avery Zweckform L7917 93x109mm²

Image:
https://de.123rf.com/lizenzfreie-bilder/90587529.html
Name:
Gießkanne und Blumen in Töpfen.
Bewässerungssymbol lokalisiert auf weißem
Hintergrund / Watering can and flowers in pots. Irrigation
symbol isolated on white background
File No.: 90587529
Copyright: nikolae
Please check license on 123RF
when using the image.

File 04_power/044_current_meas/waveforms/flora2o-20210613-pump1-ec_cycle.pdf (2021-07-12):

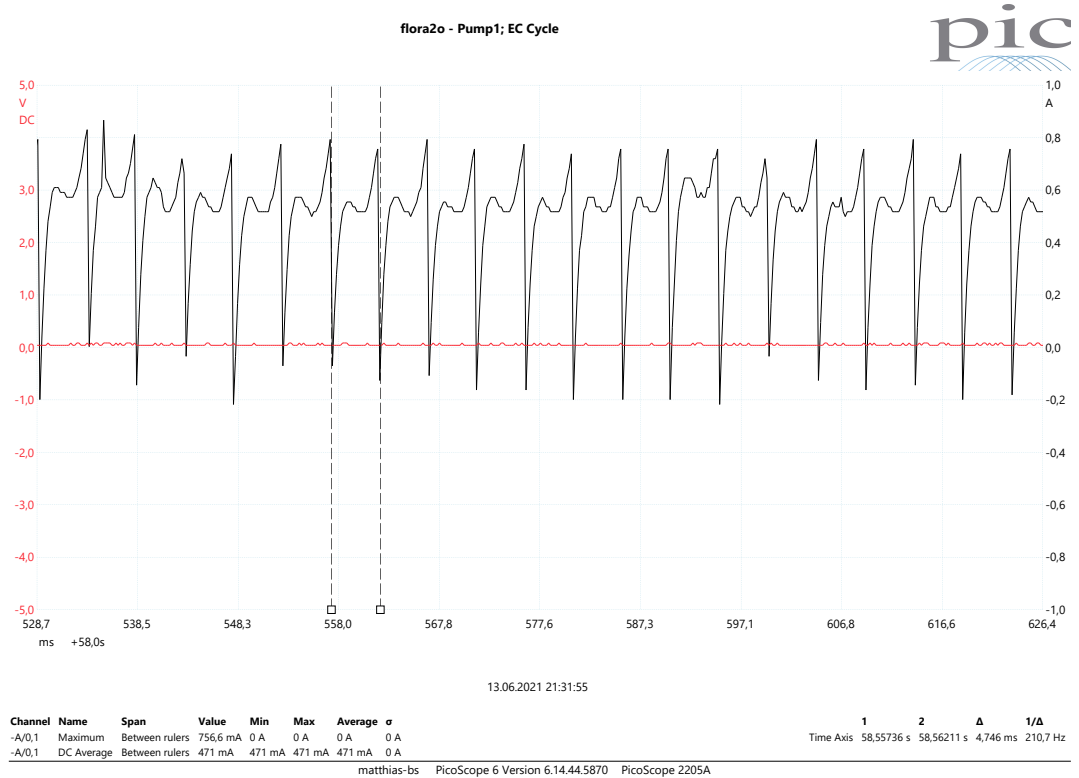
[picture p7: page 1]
Channel Name; Span; Value; Min; Max; Average σ; Maximum; Between rulers 756,6 mA 0 A; DC Average Between rulers 471 mA 471 mA 471 mA 471 mA 0 A; flora2o - Pump1; EC Cycle

Time Axis 58,55736 s 58,56211 s 4,746 ms 210,7 Hz

matthias-bs PicoScope 6 Version 6.14.44.5870 PicoScope 2205A

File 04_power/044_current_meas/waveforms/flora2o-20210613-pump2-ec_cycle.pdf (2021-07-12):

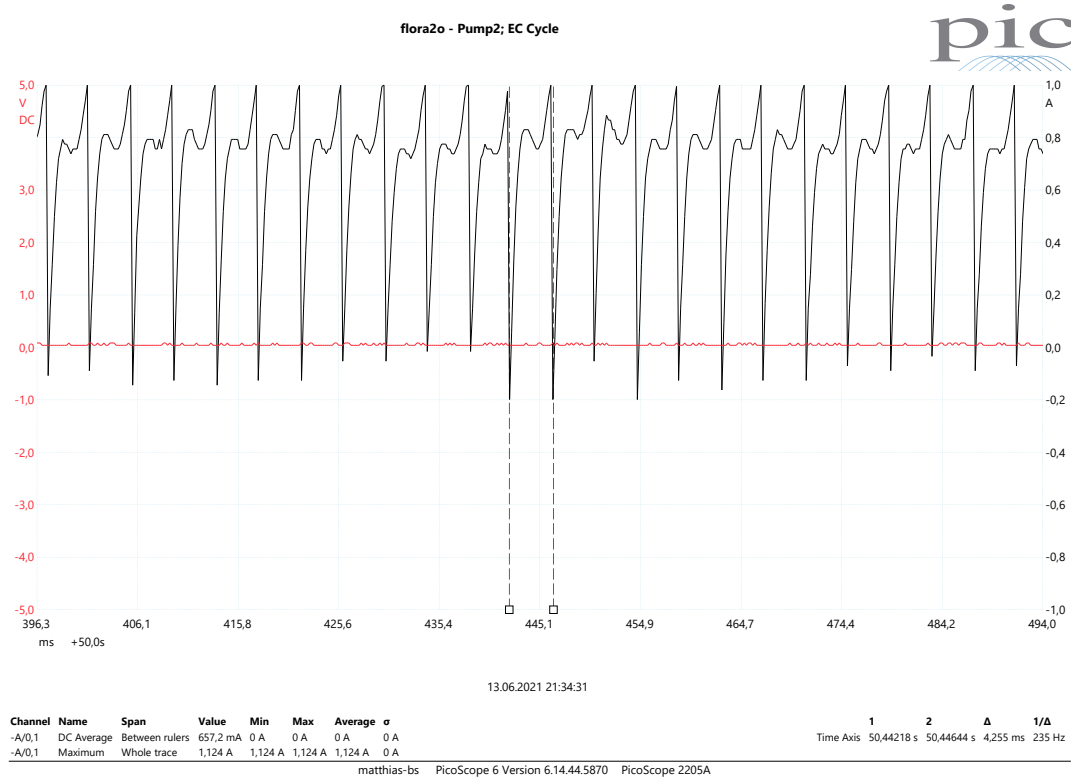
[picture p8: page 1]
Channel Name; Span; Value; Min; Max; Average σ; DC Average Between rulers 657,2 mA 0 A; Maximum; Whole trace; flora2o - Pump2; EC Cycle

Time Axis 50,44218 s 50,44644 s 4,255 ms 235 Hz

matthias-bs PicoScope 6 Version 6.14.44.5870 PicoScope 2205A

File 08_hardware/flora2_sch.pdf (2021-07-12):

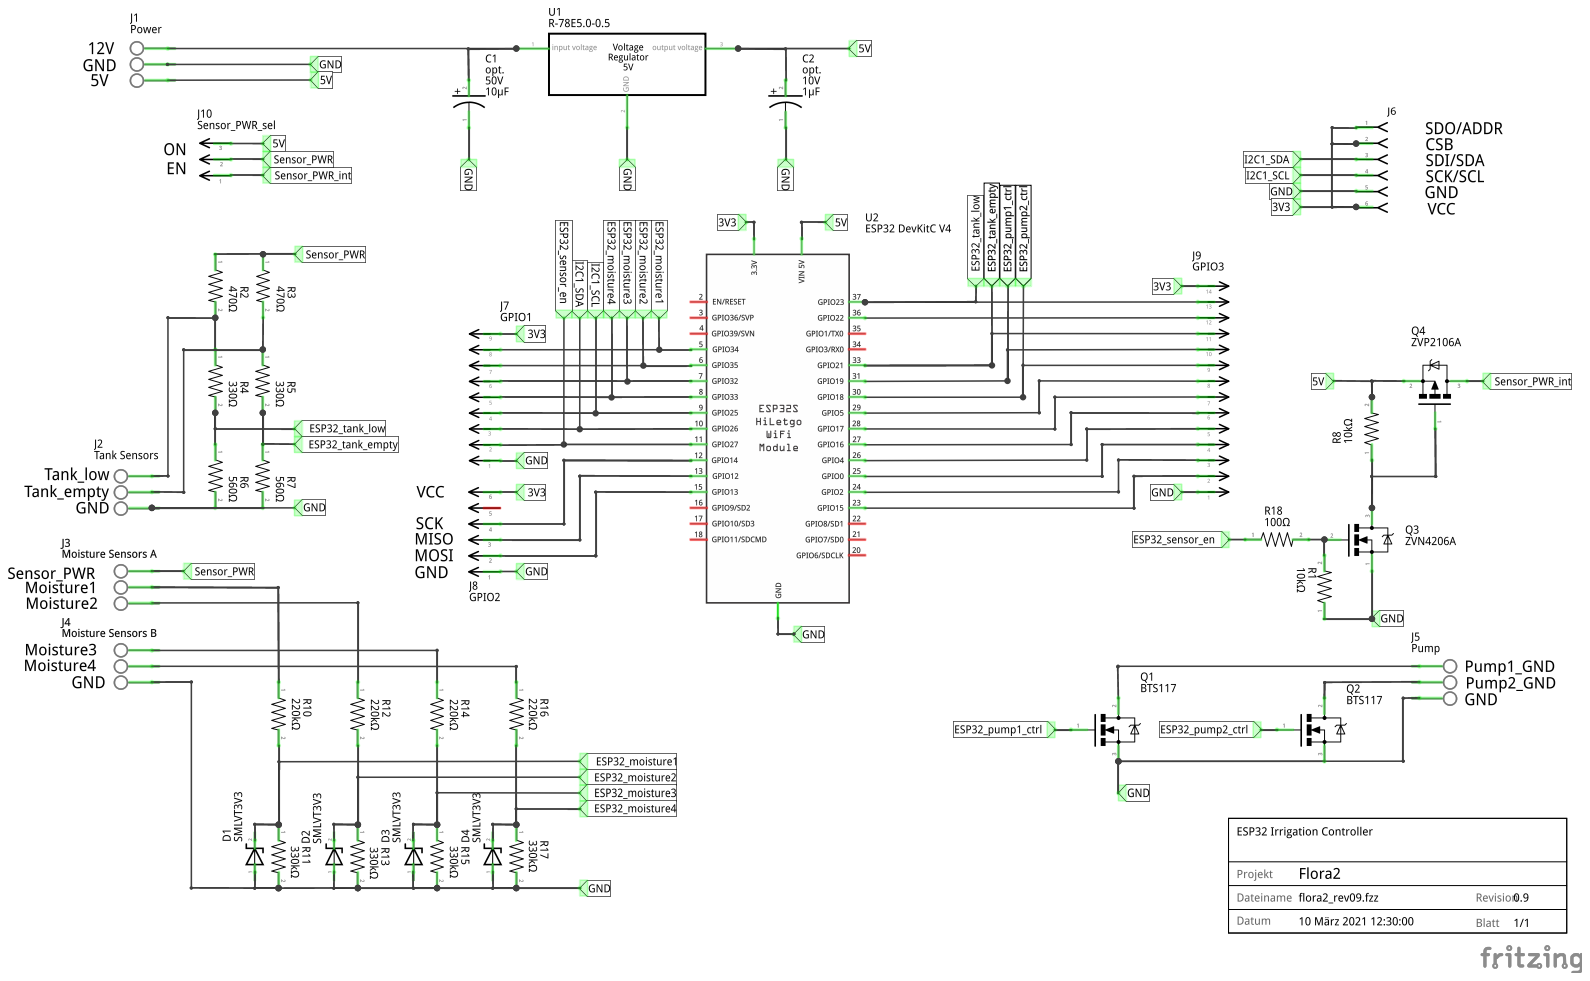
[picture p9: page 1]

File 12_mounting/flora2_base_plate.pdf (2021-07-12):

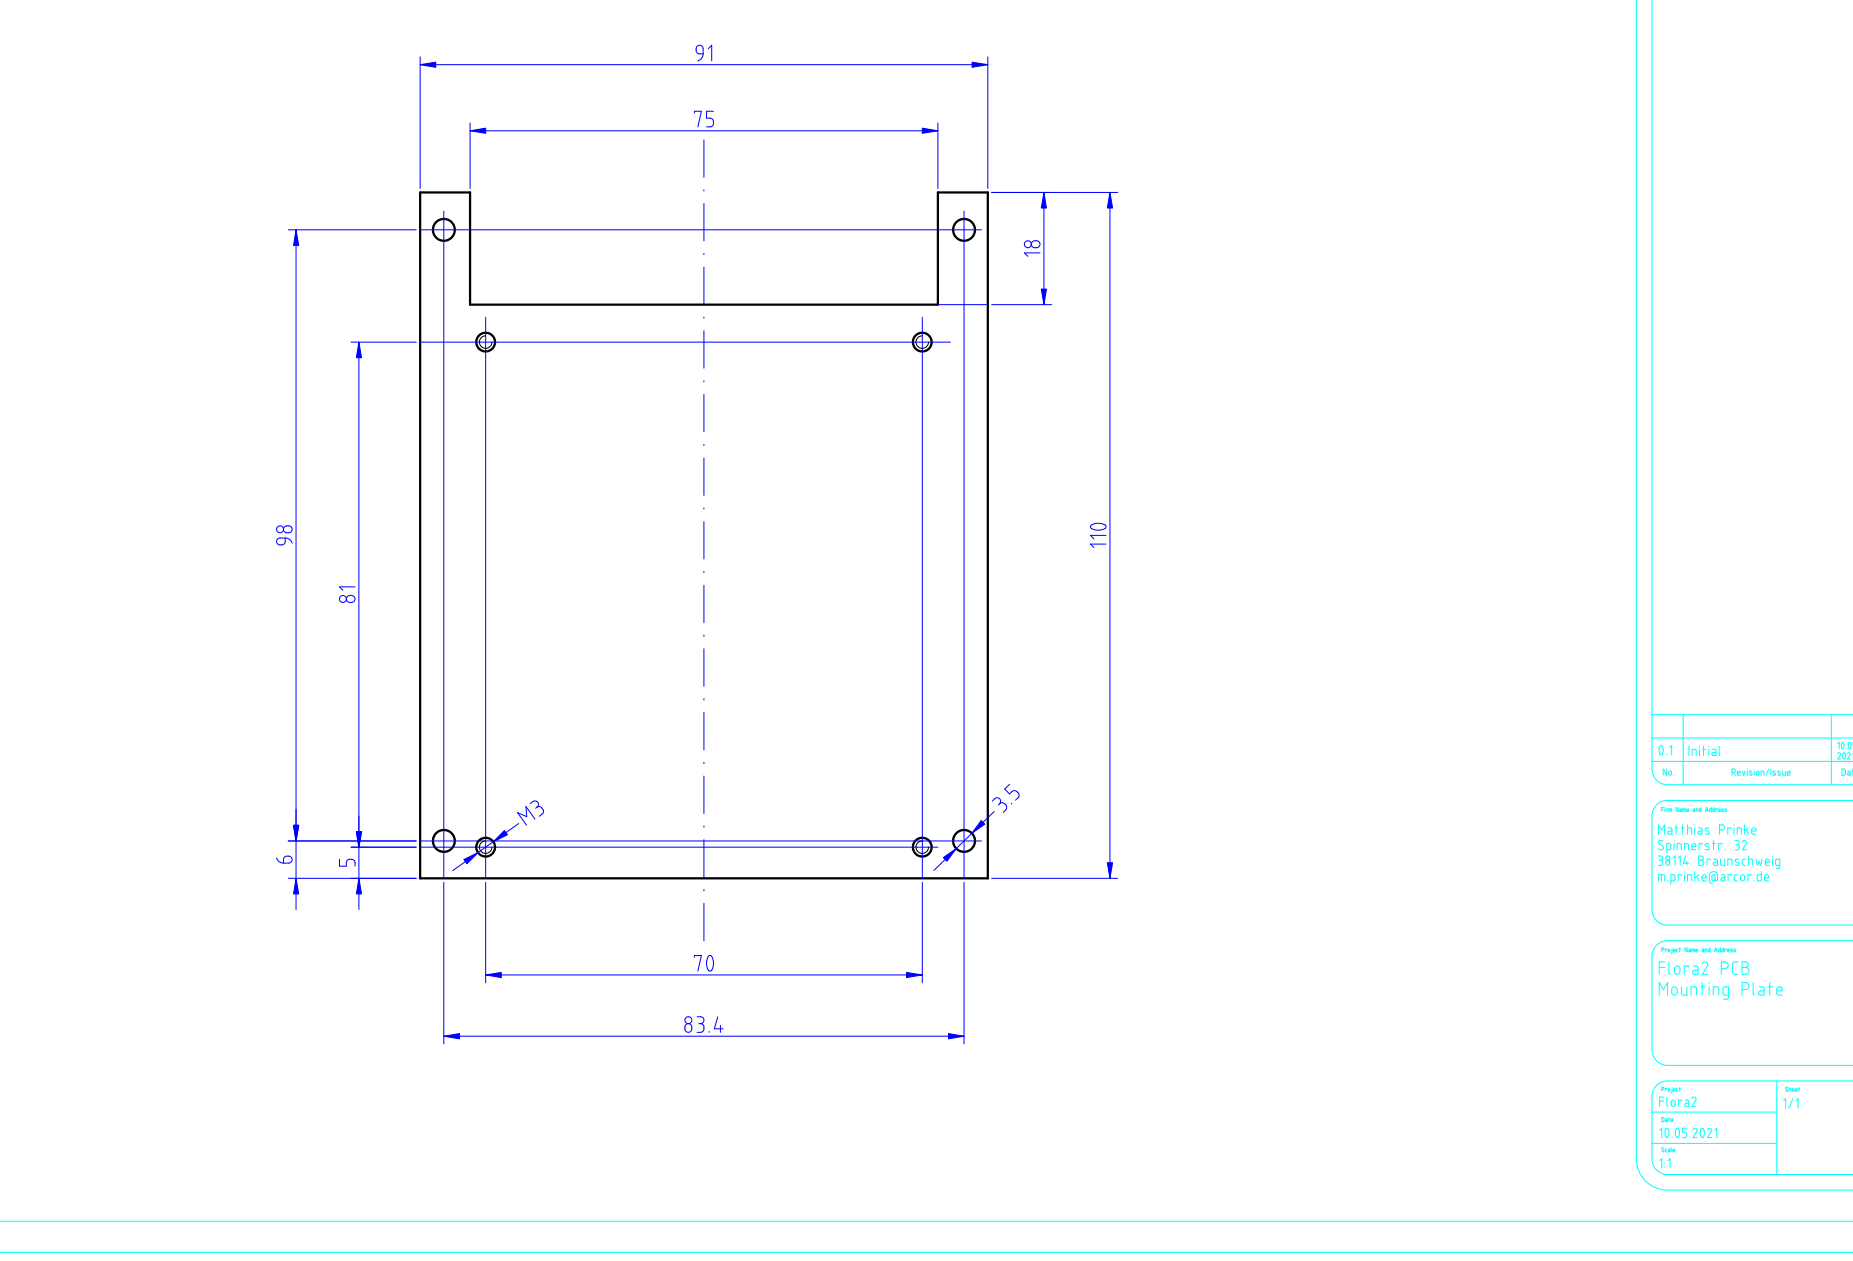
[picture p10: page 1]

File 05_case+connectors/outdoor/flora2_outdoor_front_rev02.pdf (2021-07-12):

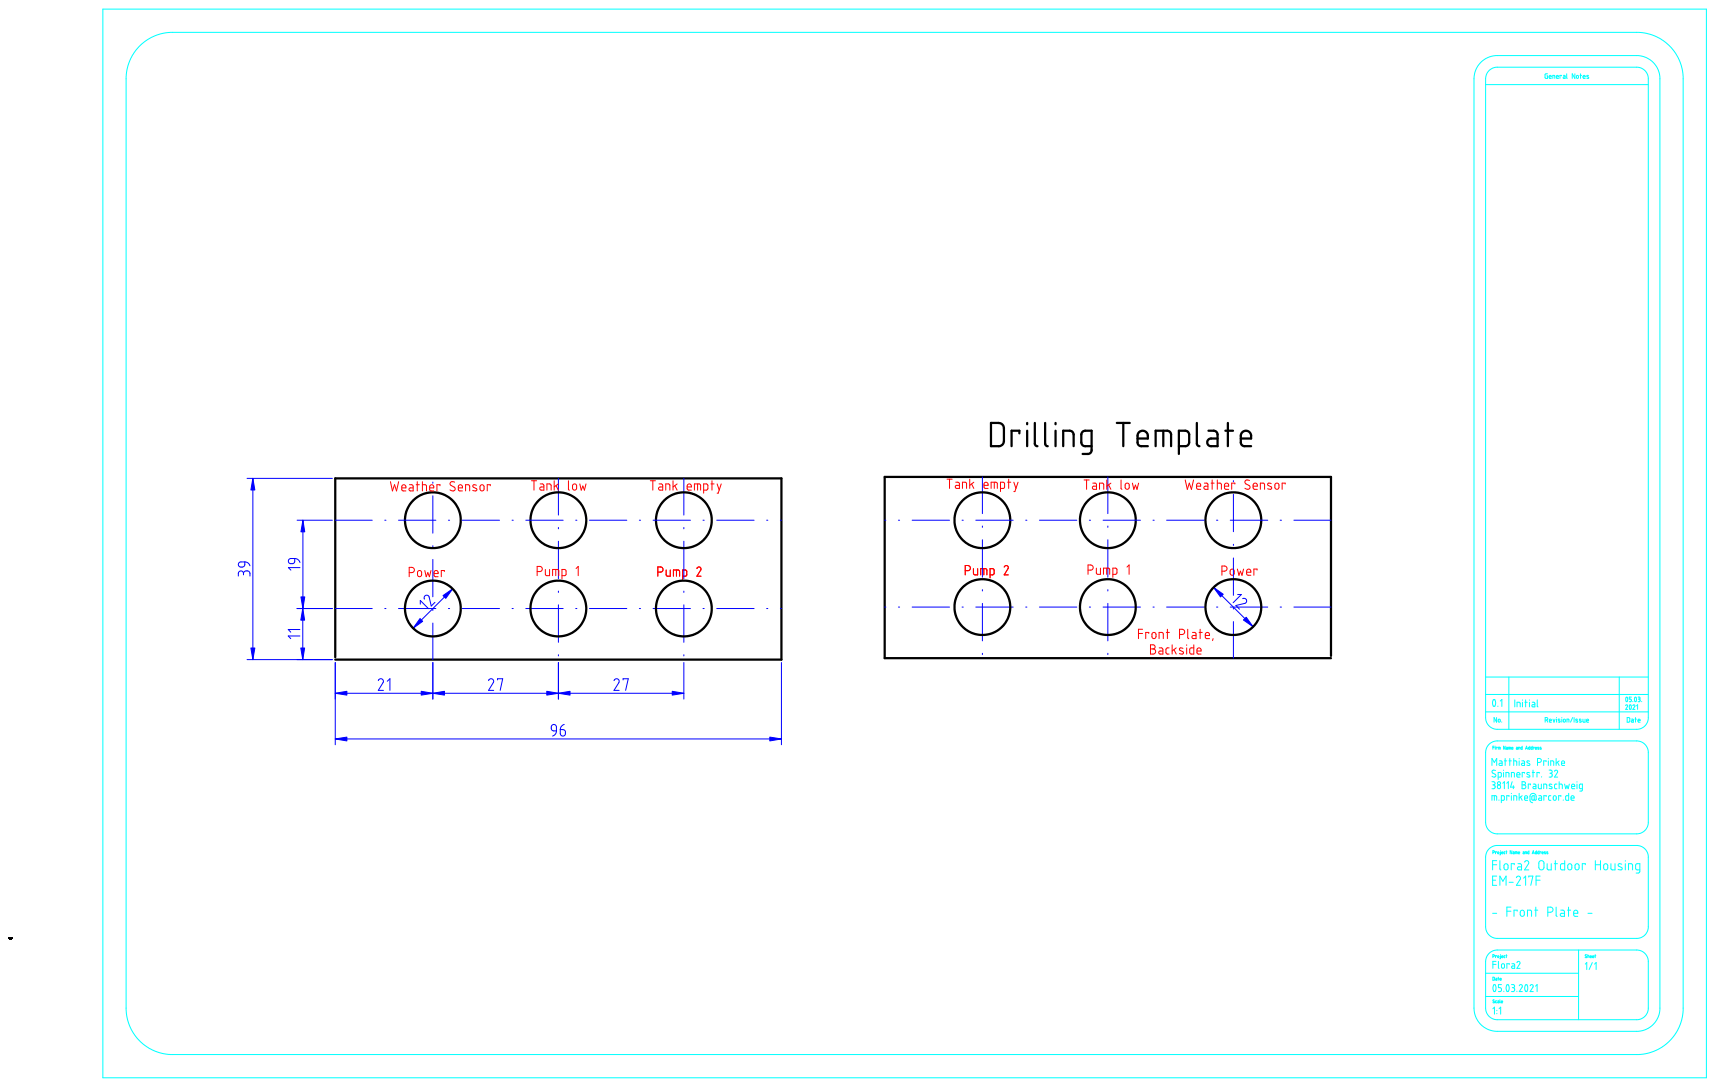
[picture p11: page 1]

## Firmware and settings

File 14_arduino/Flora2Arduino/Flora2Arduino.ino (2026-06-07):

///////////////////////////////////////////////////////////////////////////////
// Flora2Arduino.ino
//
// Flora2 — Automated plant irrigation system for ESP32
//
// Ports 09_software/_main.py (MicroPython) to Arduino/C++.
//
// Hardware (GPIO assignments in Flora2Cfg.h):
//   • Capacitive moisture sensors  ADC1 (GPIO 34/35/32/33)
//   • DS18B20 OneWire temperature  GPIO 5
//   • I2C weather sensor           SDA=26, SCL=25
//   • Pump control                 GPIO 19, 18
//   • Tank level sensors           GPIO 23 (low), 21 (empty)
//   • Sensor power rail            GPIO 27
//   • Battery voltage ADC          GPIO 35
//   • MiFlora BLE sensors          (direct GATT read via NimBLE)
// Note: On default Flora2 PCB, moisture sensor 2 and battery ADC are both on GPIO 35.
// Re-routing either signal to a different GPIO requires a hardware patch on the PCB.
//
// Required libraries:
//   NimBLE-Arduino          (h2zero)
//   ArduinoJson             (bblanchon)
//   arduino-mqtt            (256dpi)
//   OneWireNg               (pstolarz)     — when TEMPERATURE_SENSOR_EN defined
//   pocketBME280            (angrest)      — when WEATHER_SENSOR_BME280 defined
//
// MIT License — Copyright (c) 2026 Matthias Prinke
///////////////////////////////////////////////////////////////////////////////

#include <Arduino.h>
#include <esp_sleep.h>
#include <esp_efuse.h>
#include <Preferences.h>
#include <Wire.h>

#include "Flora2Cfg.h"
#include "secrets.h"
#include "src/ConfigLoader.h"
#include "src/Tank.h"
#include "src/Pump.h"
#include "src/MoistureSensor.h"
#include "src/DS1820.h"
#include "src/WeatherSensor.h"
#include "src/MiFloraSensor.h"
#include "src/Irrigation.h"
#include "src/WiFiManager.h"
#include "src/MqttManager.h"

// ─── RTC state (survives deep sleep, cleared on power-off) ───────────────────

RTC_DATA_ATTR static time_t  rtc_pump_last_run[NUM_PUMPS]   = { 0, 0 };
RTC_DATA_ATTR static bool    rtc_auto_irr_enabled            = DEF_AUTO_IRRIGATION;
RTC_DATA_ATTR static bool    rtc_sleep_disabled              = false;
RTC_DATA_ATTR static uint32_t rtc_man_irr_duration           = DEF_IRR_DURATION_MAN;
RTC_DATA_ATTR static uint32_t rtc_cycle_count                = 0;
RTC_DATA_ATTR static bool    rtc_first_boot                  = true;
// Last man_irr_cmd value (1-based pump number) that was handled this power-on session.
// Guards against re-firing if the broker reset publish fails and the retained
// message is re-delivered on the next wakeup with the same value.
RTC_DATA_ATTR static uint8_t  rtc_last_man_irr_cmd            = 0;  ///< 0 = none
// Auto irrigation duration per pump (s) — MQTT-overridable, 0 = use config.json value.
RTC_DATA_ATTR static uint32_t rtc_auto_irr_duration[NUM_PUMPS] = { 0, 0 };
// Last trigger source per pump for last_run payload: 0=unknown, 1=auto, 2=manual.
RTC_DATA_ATTR static uint8_t rtc_pump_last_trigger[NUM_PUMPS] = {
    PUMP_TRIGGER_UNKNOWN,
    PUMP_TRIGGER_UNKNOWN
};

// ─── Global objects ───────────────────────────────────────────────────────────

static AppConfig      gCfg;
static Tank           gTank(PIN_TANK_LOW, PIN_TANK_EMPTY);
static Pump           gPumps[NUM_PUMPS] = { Pump(PIN_PUMP_1, 0), Pump(PIN_PUMP_2, 1) };
static MoistureSensor gMoisture;
static DS1820         gDS1820(PIN_ONEWIRE);
static WeatherSensor  gWeather;
static MiFloraSensor  gMiFlora;
static WiFiMgr        gWiFi;

// MqttManager and Irrigation are created after config is loaded
static MqttManager*   gpMqtt       = nullptr;
static Irrigation*    gpIrrigation = nullptr;

// Plant sensor data (filled by BLE / local ADC / MQTT each cycle)
static PlantSensorData gSensorData[MAX_PLANT_SENSORS];

// ─── Helpers ─────────────────────────────────────────────────────────────────

static uint32_t measureBatteryMv()
{
#ifdef BATTERY_VOLTAGE_EN
    uint32_t sum = 0;
    for (int i = 0; i < UBATT_SAMPLES; i++) {
        sum += analogReadMilliVolts(PIN_UBATT_ADC);
        delay(5);
    }
    return (uint32_t)((float)(sum / UBATT_SAMPLES) * UBATT_DIV_FACTOR);
#else
    return 0;
#endif
}

/// Collect BLE MAC addresses from plant config into a vector.
static std::vector<std::string> buildBleAddressList()
{
    std::vector<std::string> addrs;
    for (uint8_t i = 0; i < gCfg.num_plants; i++) {
        addrs.push_back(std::string(gCfg.plants[i].address));
    }
    return addrs;
}

/// Populate gSensorData from local moisture ADC (LOCAL mode).
static void readLocalSensors()
{
    for (uint8_t i = 0; i < gCfg.num_plants; i++) {
        int pin = gCfg.plants[i].adc_pin;
        if (pin < 0) continue;
        float pct = gMoisture.getMoisture(pin);
        if (pct < 0.0f) continue;
        gSensorData[i].moisture    = (uint8_t)pct;
        gSensorData[i].valid       = true;
        gSensorData[i].last_update = time(nullptr);
        log_i("Plant[%d] moisture (local ADC): %d%%", i, gSensorData[i].moisture);
    }
}

/// Copy sensor data received via MQTT into gSensorData.
static void syncMqttSensorData()
{
    for (uint8_t i = 0; i < gCfg.num_plants; i++) {
        if (gpMqtt->mqttSensorUpdated[i]) {
            gSensorData[i] = gpMqtt->mqttSensorData[i];
            gpMqtt->mqttSensorUpdated[i] = false;
        }
    }
}

/// Enter deep sleep or busy-wait depending on config and battery state.
static void goToSleep(uint32_t battery_mV)
{
    uint32_t period = (battery_mV > 2000 && battery_mV < gCfg.general.battery_weak)
                      ? gCfg.general.processing_period2
                      : gCfg.general.processing_period;

    if (gCfg.general.deep_sleep && !rtc_sleep_disabled) {
        log_i("Deep sleeping for %lu s", (unsigned long)period);
        esp_sleep_enable_timer_wakeup((uint64_t)period * 1000000ULL);
        esp_deep_sleep_start();
        // Does not return
    } else {
        log_i("Waiting %lu s (deep sleep disabled)", (unsigned long)period);
        uint32_t ms = period * 1000UL;
        uint32_t start = millis();
        while ((millis() - start) < ms) {
            if (gpMqtt && gpMqtt->isConnected()) gpMqtt->loop();
            delay(500);
        }
    }
}

// ─────────────────────────────────────────────────────────────────────────────
// setup()
// ─────────────────────────────────────────────────────────────────────────────

void setup()
{
    Serial.begin(115200);
    delay(500);
    // Ensure timezone environment is set on every boot so localtime()/getLocalTime()
    // return the correct local time after deep-sleep resets (TZ is not retained).
    setenv("TZ", TIMEZONE_STR, 1);
    tzset();
    log_i("Flora2 Arduino v%s — boot #%lu", FLORA2_VERSION, (unsigned long)rtc_cycle_count);

    // Sensor power rail on before I2C/OneWire init
    pinMode(PIN_SENSOR_POWER, OUTPUT);
    digitalWrite(PIN_SENSOR_POWER, HIGH);
    delay(100);  // Allow sensors to stabilise

    // Load runtime configuration from LittleFS
    ConfigLoader::load(gCfg);

    // Create objects that depend on config
    gpMqtt = new MqttManager(gCfg);
    gpIrrigation = new Irrigation([&]() {
        if (gpMqtt && gpMqtt->isConnected()) gpMqtt->loop();
    });

    // Hardware init
    gTank.begin();
    for (uint8_t i = 0; i < NUM_PUMPS; i++) gPumps[i].begin();

#ifdef TEMPERATURE_SENSOR_EN
    if (!gDS1820.begin()) {
        log_w("DS1820: no devices found");
    }
#endif

    Wire.begin(PIN_I2C_SDA, PIN_I2C_SCL);
    if (gCfg.sensor.weather_sensor) {
        if (!gWeather.begin()) {
            log_w("Weather sensor init failed");
        }
    }

    // Battery check — force extended sleep if critically low
    uint32_t battMv = measureBatteryMv();
    if (battMv > 2000 && battMv < gCfg.general.battery_low) {
        log_e("Battery critically low (%lu mV) — deep sleeping 1 h", (unsigned long)battMv);
        esp_sleep_enable_timer_wakeup(3600ULL * 1000000ULL);
        esp_deep_sleep_start();
    }

    // Initialise sensor data array timestamps
    if (rtc_first_boot) {
        memset(gSensorData, 0, sizeof(gSensorData));
        // Seed RTC auto-duration from compiled-in defaults on first power-on.
        // These will be overridden by config.json values below, and later by MQTT.
        rtc_auto_irr_duration[0] = DEF_IRR_DURATION_AUTO1;
        rtc_auto_irr_duration[1] = DEF_IRR_DURATION_AUTO2;
        rtc_first_boot = false;
    }
}

// ─────────────────────────────────────────────────────────────────────────────
// loop()
// ─────────────────────────────────────────────────────────────────────────────

void loop()
{
    uint32_t battMv = measureBatteryMv();
    log_i("Battery: %lu mV", (unsigned long)battMv);

    // ── 1. Sensor power on, allow warm-up ────────────────────────────────────
    digitalWrite(PIN_SENSOR_POWER, HIGH);
    delay(200);

    // ── 2. Read weather sensor ────────────────────────────────────────────────
    WeatherData weatherData = {};
    if (gCfg.sensor.weather_sensor) {
        if (!gWeather.isReady()) {
            // Sensor rail may be enabled only during loop(); retry init after power-on.
            if (!gWeather.begin()) {
                log_w("Weather sensor re-init failed");
            }
        }
        if (gWeather.read()) {
            weatherData = gWeather.data();
        }
    }

    // ── 3. Read ambient temperature (DS1820) ──────────────────────────────────
#ifdef TEMPERATURE_SENSOR_EN
    gDS1820.requestAll();
    ambientTemp = gDS1820.getTemperatureC(0);
    log_i("Ambient: %.2f°C", ambientTemp);
#endif

    // ── 4. Read plant sensor data ─────────────────────────────────────────────
    if (gCfg.sensor.sensor_interface == SensorInterface::BLE) {
        auto addrs = buildBleAddressList();

        gMiFlora.readBattery(addrs, gSensorData, gCfg.num_plants);

        uint8_t complete = 0;
        for (uint8_t i = 0; i < gCfg.num_plants; i++) {
            if (gSensorData[i].valid_mask != 0) complete++;
        }
        log_i("BLE direct GATT: %d/%d sensors complete", complete, gCfg.num_plants);
    } else if (gCfg.sensor.sensor_interface == SensorInterface::LOCAL) {
        readLocalSensors();
    }
    // MQTT mode: sensor data collected during the MQTT session below

    // ── 5. WiFi + MQTT ────────────────────────────────────────────────────────
    bool wifiOk = gWiFi.connect();
    if (wifiOk && rtc_cycle_count == 0) {
        // First boot: sync NTP
        gWiFi.ntpSync(TIMEZONE_STR, NTP_SERVER_1, NTP_SERVER_2, NTP_SERVER_3);
    } else if (wifiOk) {
        // Re-sync periodically (every 12 h ≈ every 48 cycles at 15-min period)
        if (rtc_cycle_count % 48 == 0) {
            gWiFi.ntpSync(TIMEZONE_STR, NTP_SERVER_1, NTP_SERVER_2, NTP_SERVER_3);
        }
    }

    bool mqttOk = false;
    if (wifiOk) {
        mqttOk = gpMqtt->connect();
        if (!mqttOk) {
            log_w("MQTT connect failed - running irrigation offline this cycle");
        }
    } else {
        log_w("WiFi connect failed - running irrigation offline this cycle");
    }

    if (mqttOk) {
#ifdef HA_DISCOVERY_EN
        // Publish discovery once on first boot
        if (rtc_cycle_count == 0) gpMqtt->publishDiscovery();
#endif

        // Let incoming messages arrive (especially MQTT sensor mode)
        for (int i = 0; i < 10; i++) {
            gpMqtt->loop();
            delay(200);
        }

        // In MQTT sensor mode, copy received data to gSensorData
        if (gCfg.sensor.sensor_interface == SensorInterface::MQTT) {
            syncMqttSensorData();
        }

        // Apply any pending control commands from MQTT
        if (gpMqtt->pendingAutoIrrSet) {
            rtc_auto_irr_enabled            = gpMqtt->pendingAutoIrrValue;
            // Propagate to live config for this cycle
            gCfg.general.auto_irrigation    = rtc_auto_irr_enabled;
            gpMqtt->pendingAutoIrrSet        = false;
            gpMqtt->publishAutoIrrStatus(rtc_auto_irr_enabled);
        }
        if (gpMqtt->pendingSleepDisSet) {
            rtc_sleep_disabled          = gpMqtt->pendingSleepDisValue;
            gpMqtt->pendingSleepDisSet  = false;
            gpMqtt->publishSleepDisStatus(rtc_sleep_disabled);
        }
        if (gpMqtt->pendingManIrrDurationSet) {
            rtc_man_irr_duration               = gpMqtt->pendingManIrrDuration;
            gpMqtt->pendingManIrrDurationSet   = false;
        }
        for (uint8_t p = 0; p < NUM_PUMPS; p++) {
            if (gpMqtt->pendingAutoIrrDurationSet[p]) {
                rtc_auto_irr_duration[p]            = gpMqtt->pendingAutoIrrDuration[p];
                gpMqtt->pendingAutoIrrDurationSet[p] = false;
            }
        }

        // Some brokers or network conditions can drop the session shortly after
        // CONNECT/subscribe. Re-check before publishing state payloads.
        if (!gpMqtt->isConnected()) {
            log_w("MQTT disconnected before publish block - reconnecting");
            if (gpMqtt->connect()) {
                gpMqtt->loop();
                delay(50);
            } else {
                log_e("MQTT reconnect failed - skipping publish block this cycle");
            }
        }

        // ── 6. Publish sensor data ────────────────────────────────────────────
        if (gpMqtt->isConnected()) {
            log_i("MQTT publish block: start");
            gpMqtt->publishBattery(battMv);
            TankStatus tankStatus = gTank.read();
            uint8_t tankCode = (tankStatus == TankStatus::EMPTY) ? 0 :
                       (tankStatus == TankStatus::TANK_LOW) ? 1 : 2;
            gpMqtt->publishTank(tankCode);

            if (weatherData.valid) gpMqtt->publishWeather(weatherData);

            for (uint8_t i = 0; i < gCfg.num_plants; i++) {
                bool publishPlant = gSensorData[i].valid;
                if (gCfg.sensor.sensor_interface == SensorInterface::BLE) {
                    publishPlant = (gSensorData[i].valid_mask != 0);
                }
                if (publishPlant) {
                    gpMqtt->publishSensorData(i, gSensorData[i]);
                }
            }
            log_i("MQTT publish block: done");
        } else {
            log_w("MQTT publish block skipped: disconnected");
        }

        // ── 7. Manual irrigation (triggered by MQTT command) ─────────────────
        // pendingManIrrCmd holds the 1-based pump number from the retained
        // man_irr_cmd topic, or -1 if no message arrived this cycle.
        // We only fire if the received value differs from the last one we handled
        // (rtc_last_man_irr_cmd), preventing re-fires on every wakeup.
        // After running, we publish a retained "0" to reset the broker's stored
        // value so subsequent wakeups see no pending command.
        if (gpMqtt->pendingManIrrCmd >= 1) {
            uint8_t receivedCmd = (uint8_t)gpMqtt->pendingManIrrCmd;
            gpMqtt->pendingManIrrCmd = -1;

            if (receivedCmd != rtc_last_man_irr_cmd) {
                uint8_t pIdx = receivedCmd - 1;  // convert to 0-based
                if (pIdx < NUM_PUMPS) {
                    // Guard: record what we're about to handle before running
                    // so a crash mid-run still prevents a spurious re-fire.
                    rtc_last_man_irr_cmd = receivedCmd;
                    gpMqtt->publishManIrrStatus(pIdx, true);
                    PumpResult manualRes = gpIrrigation->manualIrrigate(
                        pIdx,
                        rtc_man_irr_duration,
                        gPumps[pIdx],
                        gTank,
                        rtc_pump_last_run[pIdx]
                    );
                    if (manualRes != PumpResult::TANK_EMPTY) {
                        rtc_pump_last_trigger[pIdx] = PUMP_TRIGGER_MANUAL;
                    }
                    gpMqtt->publishManIrrStatus(pIdx, false);
                    gpMqtt->publishPumpLastRun(
                        pIdx,
                        rtc_pump_last_run[pIdx],
                        rtc_pump_last_trigger[pIdx]
                    );
                    gpMqtt->loop();
                    // Reset broker's retained value → next wakeup sees "0", no re-fire.
                    gpMqtt->publishManIrrCmdReset();
                    rtc_last_man_irr_cmd = 0;
                }
            } else {
                log_i("man_irr_cmd %d: duplicate of last handled — ignoring", receivedCmd);
            }
        }

    }

    // ── 8. Auto irrigation ────────────────────────────────────────────────
    // Keep runtime auto-enable and duration overrides active even without network.
    gCfg.general.auto_irrigation = rtc_auto_irr_enabled;
    for (uint8_t p = 0; p < NUM_PUMPS; p++) {
        if (rtc_auto_irr_duration[p] > 0) {
            gCfg.general.irr_duration_auto[p] = rtc_auto_irr_duration[p];
        }
    }

    IrrigationDecision decisions[NUM_PUMPS];
    gpIrrigation->autoIrrigate(gCfg,
                                gSensorData,
                                gPumps,
                                NUM_PUMPS,
                                gTank,
                                rtc_pump_last_run,
                                decisions);

    bool anyScheduled = false;
    for (uint8_t p = 0; p < NUM_PUMPS; p++) {
        if (decisions[p].ran && decisions[p].result != PumpResult::TANK_EMPTY) {
            rtc_pump_last_trigger[p] = PUMP_TRIGGER_AUTO;
        }
        if (decisions[p].scheduled) anyScheduled = true;
    }

    if (gpMqtt->isConnected()) {
        // Report and publish state only when MQTT is online.
        for (uint8_t p = 0; p < NUM_PUMPS; p++) {
            if (decisions[p].ran) {
                gpMqtt->publishManIrrStatus(p, false);  // pump finished
                gpMqtt->loop();
            }
        }

        // Publish retained current pump state every cycle so subscribers
        // see "off" plus the last known run timestamp even if no pump ran.
        for (uint8_t p = 0; p < NUM_PUMPS; p++) {
            gpMqtt->publishManIrrStatus(p, false);
            gpMqtt->publishPumpLastRun(p, rtc_pump_last_run[p], rtc_pump_last_trigger[p]);
            gpMqtt->publishAutoIrrDurationStatus(p, gCfg.general.irr_duration_auto[p]);
        }
        gpMqtt->publishAutoIrrStatus(gCfg.general.auto_irrigation);
        gpMqtt->publishSleepDisStatus(rtc_sleep_disabled);
        gpMqtt->publishManIrrDurationStatus(rtc_man_irr_duration);
        gpMqtt->publishScheduledStatus(anyScheduled);

        // Final loop flush before disconnect
        gpMqtt->loop();
        gpMqtt->disconnect();
    }

    gWiFi.disconnect();

    // ── 9. Sensor power off ───────────────────────────────────────────────────
    digitalWrite(PIN_SENSOR_POWER, LOW);

    rtc_cycle_count++;
    log_i("Cycle %lu complete", (unsigned long)rtc_cycle_count);

    // ── 10. Sleep ─────────────────────────────────────────────────────────────
    goToSleep(battMv);
}

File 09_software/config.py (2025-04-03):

###############################################################################
# config.py
#
# This module provides constants as default application settings
# and the class Settings which mostly provides attributes set
# from the configuration file.
#
# It is higly recommended to leave the constants as-is and to
# modify config.ini instead!!!
#
#
# created: 01/2021 updated: 06/2021
#
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
# History:
#
# 20210117 Extracted from flora.py
# 20210208 Added more config items
# 20210209 Added inheritance from ConfigParser
# 20210211 Modified to save memory with MicroPython on ESP32
#          Changed to use own ConfigParser independend of execution environment
# 20210212 Moved 'secrets' to secrets.py
# 20210324 Improved memory handling by releasing chunks allocated by
#          ConfigParser as soon as possible and calling garbage collector
# 20210521 Added using micropython.const()
# 20210608 Added support of 2nd pump
# 20210622 Added MOIST_DIV, changed MOISTURE_MIN_VAL/MOISTURE_MAX_VAL to
#          real sensor output voltage in mV
# 20250306 Removed Removed alert/report/email configuration
# 20240403 Code quality improvements
#
# Backlog:
# - 
#
###############################################################################

from micropython import const

from ConfigParser import ConfigParser
from secrets import MQTT_USERNAME, MQTT_PASSWORD

###############################################################################
# Constants (User Area)
###############################################################################
#DEBUG               = const(0)     # False: 0 / True: 1
MEMINFO             = const(0)     # False: 0 / True: 1
VERBOSITY           = const(1)

WLAN_MAX_RETRIES    = const(5)     # max. no. of retries for (re-)connecting to WLAN
WLAN_RETRY_DELAY    = const(30)    # delay [s] between WLAN connect retries
BLE_MAX_RETRIES     = const(3)     # max. no. of retries for Bluetooth Low Energy devices
BLE_TIMEOUT         = const(12000) # timeout [ms] for Bluetooth Low Energy data access
BME280_ADDR         = const(0x76)  # I2C bus address for BME280 weather sensor

PROJECT_NAME        = 'flora'
PROJECT_VERSION     = 'V2.1.1'
PROJECT_BUILD       = '20240709'
PROJECT_URL         = 'https://github.com/matthias-bs/Flora2'


##############################################################################
# Constants (Expert Area)
##############################################################################

# GPIO settings
# Raspberry Pi
#GPIO_TANK_SENS_LOW   = const(23)
#GPIO_TANK_SENS_EMPTY = const(24)
#GPIO_PUMP_POWER      = [17, 27]
#GPIO_PUMP_STATUS     = const(22)
#GPIO_SENSOR_POWER    = const(18)
#GPIO_I2C_SDA         = const(?)
#GPIO_I2C_SCL         = const(?)

# ESP32-WROOM-32
GPIO_TANK_SENS_LOW   = const(23)
GPIO_TANK_SENS_EMPTY = const(21)
GPIO_PUMP_POWER      = [19, 18]
GPIO_PUMP_STATUS     = [99, 99] # dummy value, driver status not supported 
GPIO_SENSOR_POWER    = const(27)
GPIO_TEMP_SENS       = const(5)
GPIO_I2C_SDA         = const(26)
GPIO_I2C_SCL         = const(25)

# Config defaults
_MQTT_KEEPALIVE      = const(60)
_PROCESSING_PERIOD   = const(300)
_PROCESSING_PERIOD2  = const(600)
_MESSAGE_TIMEOUT     = const(900)
_NIGHT_BEGIN         = "24:00"
_NIGHT_END           = "00:00"
_AUTO_IRRIGATION     = const(1)
_IRR_DURATION_AUTO   = const(120)
_IRR_DURATION_MAN    = const(60)
_IRR_REST            = const(7200)
_BATT_LOW            = const(5)

# Constants for internal use
MQTT_DATA_RETAIN     = const(1)            # False: 0 / True: 1
MQTT_MAX_CYCLES      = const(20)           # max. no. of send/receive cycles
PUMP_BUSY_MAN        = const(1)
PUMP_BUSY_AUTO       = const(2)
MOISTURE_ADC_PINS    = [34, 35, 32, 33]
MOISTURE_MIN_VAL     = const(1250)
MOISTURE_MAX_VAL     = const(900)
UBATT_ADC_PIN        = const(35)           # ACD pin - mutually exclusive with any other use
UBATT_DIV            = 100/(100+200)       # Voltage divider R1 / (R1 + R2) -> V_meas = V(R1 + R2); V_adc = V(R1)
MOIST_DIV            = 330/(330+220)       # Voltage divider R1 / (R1 + R2) -> V_meas = V(R1 + R2); V_adc = V(R1)
VREF                 = None                # V_ref in mV or None for eFuse calibration value
UBATT_SAMPLES        = const(10)           # no. of samples for averaging


##############################################################################
# Global variables
##############################################################################
settings = None
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

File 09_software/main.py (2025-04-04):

###############################################################################
# main.py
# Plant monitoring and irrigation system using Raspberry Pi / Espressif ESP32
#
# - based on data provided by Mi Flora Plant Sensor MQTT Client/Daemon
# - controls water pumps for irrigation
# - monitors water tank - two levels, low and empty
# - provides control/status via MQTT
# - sends alerts via SMTP emails
#
# MQTT subscriptions:
#     <base_topic_sensors>/<sensor_name>     (JSON encoded data)
#     <base_topic>/man_report_cmd            (-)
#     <base_topic>/man_irr_cmd               (1|2)
#     <base_topic>/man_irr_duration_ctrl     (<seconds>)
#     <base_topic>/auto_irr_ctrl             (0|1)
#     <base_topic/sleep_dis_ctrl             (0|1)
#
# MQTT publications:
#     <base_topic>/status                    (online|offline|idle|dead$)
#     <base_topic>/man_irr_stat              (0|1)
#     <base_topic>/man_irr_duration_stat     (<seconds>)
#     <base_topic>/auto_irr_stat             (0|1)
#     <base_topic>/tank                      (0|1|2)
#     <base_topic>/<sensor_name>             (JSON encoded data)*
#     <base_topic>/<sensor_name>/moisture    (<percent>)§
#     <base_topic>/temperature               (<degC>)+
#     <base_topic>/weather                   (JSON encoded data)+
#     <base_topic>/ubatt                     (<mV>)+
#     <base_topic>/sleep_dis_stat            (0|1)
#
# $ via LWT
# * only with local Mi Flora (flower care) sensors
# § only with local analog soil moisture sensors
# + optional
#
# created: 02/2020 updated: 07/2021
#
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
# History:
#
# 20200226 Tank level sensor input working
# 20200302 Config file reading implemented
# 20200304 MQTT client for plant sensor data working
# 20200309 E-mail report implemented, pump control via MQTT message working
# 20200325 Sending e-mail report based on sensor/plant data implemented
# 20200421 Specific irrigation time for automatic/manual mode added
#          MQTT feedback messages for manual irrigation time setting added
#          Handling of sensor time-out added
# 20200428 Added switching auto reporting and auto irrigation on/off via MQTT
# 20200502 Rev. 1.0, Initial release
# 20200504 Added night mode
# 20210105 Fixed manual irrigation
#          Messages were queued while irrigation was already in progress,
#          which led to multiple irrigation cycles where only one was desired.
#          Added message 'man_irrigation_status'
# 20210106 Code cleanup
#          Added tank object as parameter to Pump class constructor -
#          the mapping between pump and tank will never change during run time
# 20210116 Major refactoring and switch to object oriented implementation
#          Functional improvement of E-mail reporting
# 20210117 Split source file into multiple modules
#          Replaced set-/get-methods by properties
# 20210118 Renamed MQTT topics
# 20210202 Changed ConfigParser usage for compatibility with MicroPython
#          Various modifications for MicroPython
# 20210203 Added e-mail reporting with MicroPython
# 20210207 Changed report to send email in smaller chunks
#          due to ESP memory constraints
# 20210208 Replaced config by settings (mostly)
# 20210209 Moved config to settings
# 20210210 Added SSL to MicroPython / uMQTT implementation
# 20210211 Workaround for Out-of-Memory in umail.SMTP()
#          (Only occurs with MQTT over SSL):
#          MQTT client disconnect -> send mail -> MQTT reconnect
# 20210212 Added re-connection after WLAN interruption
#          (not fully working)
# 20210213 uMQTT function calls cluttered with try/except - needs reworking
# 20210315 Added support for analog soil moisture sensors
# 20210316 Added connecting to WLAN access point from list in secrets.py
# 20210317 Modified status report for moisture-only sensor sensors
#          Added support for one-wire temperature sensors
# 20210318 Moved MQTT code to module flora_mqtt
# 20210321 Preparations for retaining state while in deep sleep mode (ESP32)
# 20210323 Implemented deep sleep mode (ESP32)
# 20210324 Improve sleep mode on ESP32 - added auto_report & auto_irrigation
#          to saved state
# 20210329 Fixed running pump by adding MQTT pings (uMQTT)
# 20210508 Added support of MiFlora Bluetooth Low Energy plant sensors
# 20210509 Added support of BME280 temperature/humidity/pressure sensor
# 20210511 Added optional battery voltage measurement
# 20210519 Modified access to tank/pump
# 20210521 Code restructured
#          Changed uMQTT implementation to micropython-umqtt.robust2
#          (https://github.com/fizista/micropython-umqtt.robust2)
# 20210531 Modified MQTT protocol handling
#          Added status message
# 20210608 Added control of 2nd pump
# 20210609 Modified load_state()/save_state() and added items
# 20210622 Updated adc1_cal, improved analog moisture sensor data evaluation
#          Added BLE exception handling
# 20210711 Fixed sending of MQTT status messages and handling of 
#          boolean fallback values
#          Fixed auto irrigation
# 20240709 Updated include statements for MicroPython v1.23.0 compatibility
#          Prevent sleep mode if battery voltage input is disconnected
# 20250305 Removed alert, replaced report email by MQTT message
#          Modified string formatting, code improvements
#          Removed conditional code execution with support of non-micropython
#          platforms
# 20250330 Added MQTT discovery messages
# 20250402 Code improvements
# 20250404 Changed wifi to Singleton class
#
# Backlog:
# - fix MQTT over TLS
# - add daily min/max of sensor values
# - compare light value against daily average
#
# Notes:
#
# - adding Wi-Fi Manager failed due to lack of memory
#
###############################################################################

import sys
import json
import binascii
import time
from time import sleep

from wifi import wifi_manager
import miflora
from miflora import Mi_Flora
import machine
import ntptime
import uerrno
from bluetooth import BLE
from machine import reset
if sys.implementation.name == "micropython":
    import gc
if sys.platform == "esp32":
    import adc1_cal
else:
    from gpio import GPIO

# Flora specific modules
import config as cfg
from config import MEMINFO, VERBOSITY
import flora_mqtt as m_mqtt
from garbage_collect import gcollect, meminfo

import irrigation as m_irrigation
import moisture as m_moisture
from print_line import print_line
import pump as m_pump
import report as m_report
import sensor as s
import sensor_power as m_sensor_power
import tank as m_tank
import temperature as m_temperature
import weather as m_weather
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

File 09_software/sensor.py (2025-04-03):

###############################################################################
# sensor.py
#
# This module provides the Sensor class
#
# - stores sensor data
# - stores plant data (i.e. limits for environmental conditions)
# - compares sensor data with plant data
# - allows to check low battery, sensor data timeout and sensor data valid
#
# created: 01/2021 updated: 07/2021
#
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
# History:
#
# 20210117 Extracted from flora.py
# 20210318 Added update_moisture_sensor() and update_temperature_sensor()
# 20210508 Added data()
# 20210509 Added attribute address
# 20210523 Added config_error()
# 20210605 Added attribute pump
# 20210609 Added property <state>
# 20210712 Fixed setting of attribute pump in init_plant() -> integer!
#
# Backlog:
# - 
#
###############################################################################

from time import time
from print_line import print_line

import json
import config as m_config

##############################################################################
# Global variables
##############################################################################
sensors = None
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

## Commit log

2021-07-12 V1.0-p1
    Patches p1:
    1. added R1:
    R1.1->Q3.G R1.2->GND
    2. Q4 Footprint:
    (current->target)
    G->D
    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
2021-07-12 Add files via upload
    S->G
    D->S
    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
2021-07-12 Bill of Materials (20210311)
    [flora2_bom.ods]
2024-07-09 Added second channel/pump
2024-07-09 Changed package names, prevent sleep mode if battery voltage input is disconnected
    [main.py]
2025-03-05 Fixes/code improvements, changed report from mail to MQTT
    [main.py]
2025-03-05 Added M5Stack ENV III sensor
2025-03-30 Fixed SHT30 exception handling
    [weather.py]
2026-06-07 Add .gitignore for Arduino build artifacts and credentials
2026-06-07 Added tasks/scripts for Copilot Arduino compiling
2026-06-07 Implement irrigation and sensor management classes for automated plant care
2026-06-07 Add vendored I2C_Class, QMP6988, and SHT3X implementations for sensor communication
2026-06-07 Add DS1820 temperature sensor driver implementation
2026-06-07 Add configuration file for Flora2 Arduino runtime settings
2026-06-07 Add package.json for Flora2 Arduino project configuration
2026-06-07 Add configuration files for Flora2 Arduino project
2026-06-07 Add README documentation for Flora2 Arduino project
2026-06-07 Add initial implementation of Flora2 Arduino project for automated irrigation
2026-06-07 Clarify Arduino sketch entrypoint path in README
2026-06-07 Add CI workflow for Arduino compilation
2026-06-07 Implement stale sensor safeguard for auto irrigation and update documentation
2026-06-07 Fix docstring formatting in arduino_compile_helper.py
2026-06-07 Enforce huge app partition for ESP32 in fqbn handling
2026-06-07 Add FQBN usage log for compile action in arduino_compile_helper.py
2026-06-08 Add opt-in insecure TLS fallback when CA loading fails
    [Flora2Cfg.h]
2026-06-09 Add error handling for MQTT initialization and message processing
    [flora_mqtt.py]
2026-06-09 Fix circular dependency by changing mqtt import to local scope in irrigation.py
    [irrigation.py]
2026-06-09 Add data length check in read_sensor_done to handle short data
    [miflora.py]
2026-06-09 Fix circular dependency by moving mqtt import to local scope in pump.py
    [pump.py]
2026-06-09 Add error handling for sensor access in Temperature class
    [temperature.py]
2026-06-09 Improved error handling for I2C initialization and sensor access
    [weather.py]
2026-06-09 Add _secrets.h and _config.json to .gitignore for Arduino project
2026-06-09 Add root_ca.pem to .gitignore for Arduino project
2026-07-08 Add weather read retries to improve sensor reliability

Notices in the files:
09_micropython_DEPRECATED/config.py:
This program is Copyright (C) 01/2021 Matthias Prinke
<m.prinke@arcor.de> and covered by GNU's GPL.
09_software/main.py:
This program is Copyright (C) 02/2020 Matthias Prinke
